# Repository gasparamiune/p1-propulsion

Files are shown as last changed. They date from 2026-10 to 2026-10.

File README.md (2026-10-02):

# P1-J — Waterjet eléctrico inboard para el jet boat de Jorge (2,30 m)

> Paquete de ingeniería del prototipo: cálculo, CAD paramétrico con verificación automática (estado abajo), planos,
> BOM, firmware y pruebas. Todo se regenera desde [`inputs.yaml`](inputs.yaml) con `python run_all.py`. Los números de
> este README se actualizan solos desde `resultados/*.json` (marcadores `<!--V:…-->`).
> **Visor 3D para Jorge** (ensamblado, explotado, pieza por pieza y demo): `04_diseno/visor/` — publicado
> como página web (link en la descripción del PR).

## Resumen ejecutivo

1. **Qué es:** el waterjet que pidió Jorge, rediseñado para que funcione: toma enrasada **entera a proa del impulsor** (su comentario: la rejilla del plano estaba detrás), rampa de 27°, impulsor inox Ø<!--V:sizing.selection.D_imp_mm:.0f-->132<!--/V--> de 5 álabes directo a un motor refrigerado por agua, estator con buje de agua, tobera Ø<!--V:sizing.selection.D_noz_mm:.0f-->87<!--/V-->, boquilla ±25° y bucket de reversa obligatorio (Al 5083 de <!--V:manifest.params.REV_t:g-->8<!--/V--> mm, trabado arriba/abajo por dos émbolos propios con perno Ø<!--V:manifest.params.REV_lock_pin_d:g-->16<!--/V--> que se liberan juntos con un gatillo; cada traba sola aguanta la reversa: D-17c/D-17d; la oreja de la boquilla todavía no llega a FS 2 en el FEA, ver abajo). 12S / 38,4 V (< 50 V CC).
2. **Prestaciones (modelo, sin validar en agua) — el punto débil es el planeo:** con la resistencia **nominal** el bote planea (margen <!--V:sizing.verdict.hump_margin_min_nominal:.0%-->4%<!--/V-->, se piden ≥ 10 %), tarda <!--V:sizing.verdict.t_to_plane_nominal_s:.0f-->23<!--/V--> s y sostiene **<!--V:sizing.verdict.vmax_cont_kmh.nominal:.1f-->24.0<!--/V--> km/h** (~<!--V:sizing.verdict.vmax_peak_kmh.nominal:.0f-->28<!--/V--> km/h por ratos). Con la resistencia **alta** (método sin validar para este casco corto, 02 §3) **no llega a planeo pleno** (se queda en <!--V:sizing.verdict.V_eq_peak_high_kmh:.0f-->20<!--/V--> km/h a fondo y <!--V:sizing.verdict.vmax_cont_kmh.high:.0f-->18<!--/V--> km/h con potencia continua). Ninguna combinación de motor/batería < 50 V cumple el 10 %: lo que lo arregla es el bote — <!--V:sizing.verdict.recovery_mass_text:s-->21 kg menos<!--/V--> o <!--V:sizing.verdict.recovery_lwl_text:s-->L_wl ≥ 1,98 m<!--/V--> (02 §3.2). Lo decide la prueba T4. Autonomía: <!--V:sizing.energy.t_top_min:.0f-->37<!--/V--> min a fondo o <!--V:sizing.energy.t_legal_h:.1f-->2.4<!--/V--> h a 5 kn; empuje a punto fijo <!--V:sizing.performance.bollard_N:.0f-->765<!--/V--> N.
3. **Recomendación:** pedir cotización de la **AWT JT132** (la bomba de la foto de Jorge) con este mismo tren eléctrico: gana la matriz de arquitectura en el <!--V:arch.mc_win_frac.B:.0%-->62%<!--/V--> del Monte Carlo, da <!--V:cmp.B_vmax_kmh:.1f-->26.8<!--/V--> km/h (≈ A ± la curva de AWT, que no está publicada: no es una ventaja demostrada) y baja el costo a ~<!--V:cmp.B_total_eur_min:.0f-->7774<!--/V-->–<!--V:cmp.B_total_eur_max:.0f-->8338<!--/V--> € contra <!--V:bom.total_eur:.0f-->11837<!--/V--> € de construir la bomba propia (<!--V:bom.verified_frac_of_subtotal:.0%-->30%<!--/V--> del subtotal con precio verificado; el resto son servicios de taller a cotizar).
4. **Riesgo n.º 1 — el casco, no la propulsión:** con 0,80 m de manga y el piloto sentado alto, GM ≈ <!--V:sizing.hydrostatics.GM_m:.3f-->0.010<!--/V--> m y capacidad (33 CFR 183.33) de <!--V:sizing.capacity.persons_gear_kg:.0f-->46<!--/V--> kg: **puede volcar**. Ensayo de escora antes de motorizar; probablemente haya que ensanchar el casco o bajar el asiento.
5. **Legal (Dinamarca):** ≤ 5 kn a < 300 m de la costa (perfil "costa" por defecto en el firmware), 4 kn en Als Sund; no es speedbåd (< 19 kW) y probablemente no es "vandscooter" (piloto dentro del casco): confirmar por escrito (research/R13 §8).
6. **Honestidad:** todo está verificado *en software* (CAD de <!--V:manifest.totals.n_parts:d-->65<!--/V--> piezas sin interferencias en <!--V:verify.n_pair_checks:d-->14160<!--/V--> pares×estados, FS ≥ 2 metal / ≥ 3 PETG, tests). **Nada está probado físicamente**; los primeros pasos están en [PENDIENTES_GASPAR.md](PENDIENTES_GASPAR.md).

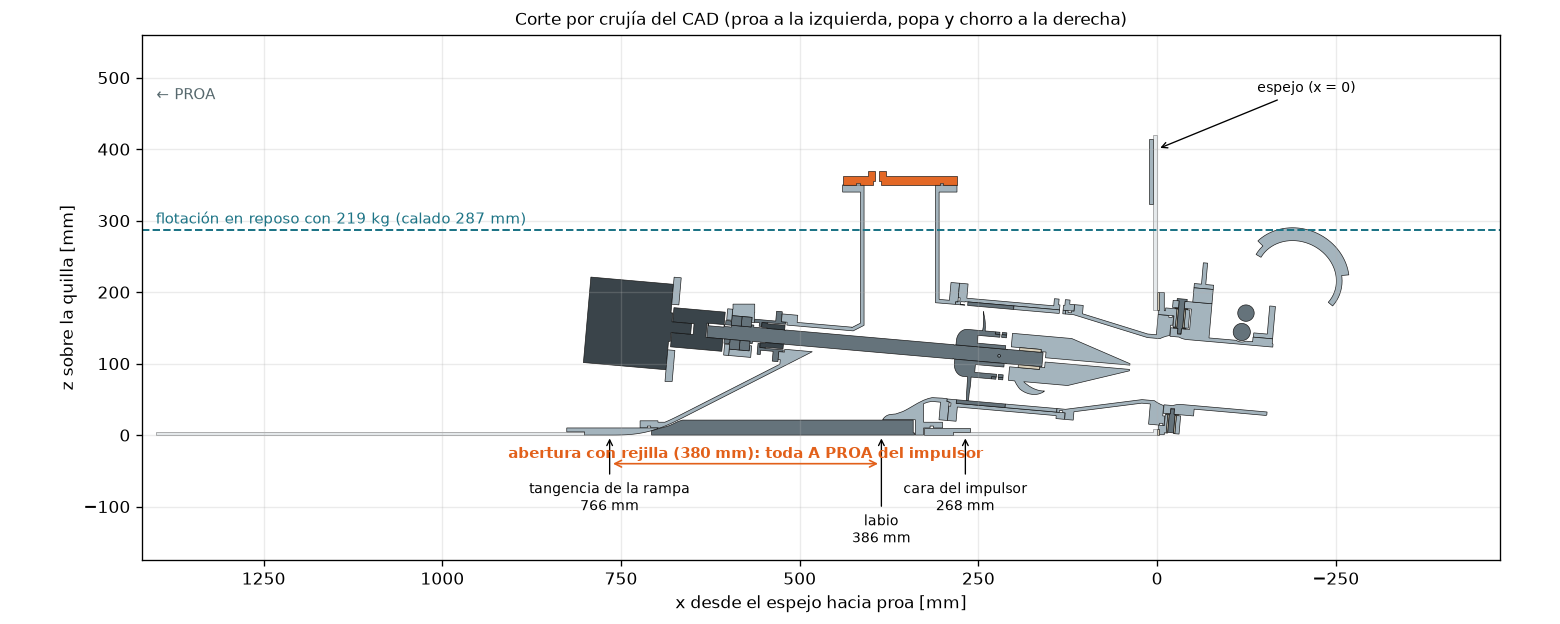
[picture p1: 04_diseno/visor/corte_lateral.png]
Corte por crujía del CAD


## Comprar vs construir

| Opción | Costo total del sistema | V máx. sostenida | Unidad de jet | Comentario |
|---|---|---|---|---|
| **A — bomba propia (este paquete)** | <!--V:bom.total_eur:.0f-->11837<!--/V--> € ≈ <!--V:bom.total_dkk:.0f-->88489<!--/V--> DKK [CALCULADO: bom.py] | <!--V:cmp.A_vmax_kmh:.1f-->24.0<!--/V--> km/h | <!--V:cmp.A_jet_mass_kg:.1f-->22.0<!--/V--> kg | Impulsor y estator CNC 5 ejes + soldaduras: <!--V:bom.services_eur:.0f-->4015<!--/V--> € de servicios de taller [ESTIMADO] sin cotizar |
| **B — AWT JT132 + este tren** | <!--V:cmp.B_total_eur_min:.0f-->7774<!--/V-->–<!--V:cmp.B_total_eur_max:.0f-->8338<!--/V--> € [CALCULADO; precio de la JT132 ESTIMADO] | <!--V:cmp.B_vmax_kmh:.1f-->26.8<!--/V--> km/h (≈ A ± curva AWT) | 12 kg [VERIFICADO: R11 §4] | Trae toma, dirección y reversa; pedir brida, altura del eje y curva de la bomba |
| Lampuga Air (jet boat eléctrico comercial de 2,30 m) | no verificado | ≤ 50 km/h [VERIFICADO: R12] | — | Referencia: 10 kW, 3,6 kWh |

Detalle y matriz ponderada: [03_arquitectura.md](03_arquitectura.md).

## Estado (verificado / no verificado)

| Ítem | Estado |
|---|---|
| Pipeline `run_all.py` (sizing → CAD → FS → planos → verify → BOM → arquitectura → comparación → electrónica → visor → docs) | Ejecuta con exit 0 (bitácora en PROGRESS.md) |
| Dimensionamiento: masas, estabilidad, Savitsky + joroba, waterjet con curva de bomba, cavitación, energía, térmico, eje, pasador | [CALCULADO] `sizing.py`; [02_calculos.md](02_calculos.md) — **calibrar con pruebas T2–T4** |
| CAD: <!--V:manifest.totals.n_parts:d-->65<!--/V--> piezas, STEP + STL, sólidos válidos, impresas ≤ 210×210×260 | [VERIFICADO en software] `verify_parts.py` |
| Interferencias: boquilla −25/0/+25° × bucket arriba/abajo, contra bomba, toma, tren y casco de referencia | [VERIFICADO en software] |
| FS ≥ 3 (impresas) / ≥ 2 (metal) por caso de carga | [CALCULADO] `structural.py` (02 §9); FEA de las piezas críticas en `04_diseno/fea/`. Bucket y boquilla con el criterio de traba única (cada traba sola con todo el momento del chorro, auditoría ronda 4) y el pivote de la ronda 5 (D-17d; en dos piezas, casquillo + muñón, desde la re-auditoría del cierre: auditoria.md MECH-1): cálculo a mano sin filas bajo objetivo; FEA fino: bucket P1-REV-01 FS <!--V:fea.piezas.P1-REV-01.FS_min:.2f-->2.07<!--/V-->, boquilla P1-STE-01 FS <!--V:fea.piezas.P1-STE-01.FS_min:.2f-->2.52<!--/V--> (objetivo 2; desde el cierre de la ronda 5 con el cuerpo del émbolo ajustado Ø<!--V:manifest.params.REV_lock_bore_d:g-->24<!--/V--> H7/h6, sin rosca ni precarga, el piloto Ø<!--V:manifest.params.REV_sp_pilot_d:g-->24<!--/V--> y lóbulos engrosados en las orejas: auditoria.md R5-N1/R5-N5, D-17d) |
| Firmware del acelerador (bucket, perfiles costa/abierto, limpieza de rejilla, kill switch) | [VERIFICADO en software] 69 tests; **sin compilar para AVR** (sin toolchain aquí) |
| Precios | <!--V:bom.verified_frac_of_subtotal:.0%-->30%<!--/V--> del subtotal verificado (research/R11, R08a/b); servicios de taller [ESTIMADO] |
| Casco de Jorge | **Leído de un plano sin escala única: medir todo** (PENDIENTES P0) |
| Estabilidad, estanqueidad, pruebas en agua | **[NO EJECUTADO] — pendiente físico** |

## Cómo correr

```bash
pip install -r requirements.txt          # núcleo (build123d, numpy, trimesh, openplaning, …)
python run_all.py                        # todo, incl. FEA fino: más de una hora; --fast = mallas gruesas y SIN FEA; --skip-render
pytest -q                                # tests (P1_SKIP_SLOW=1 salta la regeneración completa)
```
Tiempo del corrido completo: más de una hora [ESTIMADO]. Solo el FEA fino de las 5 piezas registra <!--V:fea.meta.tiempo_total_s:.0f-->2890<!--/V--> s
[CALCULADO: `meta.tiempo_total_s` de `04_diseno/fea/resultados_fea.json`], y el CAD, los planos y `verify` suman varios minutos más; con `--fast` el
FEA no corre y quedan los resultados anteriores.
Cambiar cualquier dato en `inputs.yaml` (p. ej. `boat.bottom_thickness_mm`, `waterjet.axis_height_m`,
una batería o un motor nuevo) y volver a correr regenera cálculos, selección, geometría, planos, BOM,
visor y documentos (probado: `tests/test_regeneration*.py`, ver [auditoria.md](auditoria.md) §Regeneración).

## Mapa del repositorio

| Archivo | Contenido |
|---|---|
| [01_investigacion.md](01_investigacion.md) + `research/` | Plano de Jorge auditado, toma, métodos de bomba y planeo, componentes y precios, normativa DK |
| [02_calculos.md](02_calculos.md) + `sizing.py`, `p1calc/` | Memoria de cálculo completa |
| [03_arquitectura.md](03_arquitectura.md) | Requisitos, matriz ponderada, comprar vs construir, qué se imprime/mecaniza/compra, riesgos |
| [04_diseno/](04_diseno/README.md) | `params*.py`, `piezas/`, `build_all.py`, `verify_parts.py`, `structural*.py`, planos, electrónica, visor |
| [05_fabricacion.md](05_fabricacion.md) + `prusaslicer/` | Impresión, mecanizado, soldadura, CNC, anodizado, probetas |
| [06_ensamblaje_y_pruebas.md](06_ensamblaje_y_pruebas.md) + [checklist_salida.md](checklist_salida.md) | Montaje, cambios de casco, pruebas T0–T4, FMEA, mantenimiento |
| [07_roadmap_P2.md](07_roadmap_P2.md) | Próxima iteración con disparadores medibles |
| [decisiones.md](decisiones.md) · [auditoria.md](auditoria.md) · [PENDIENTES_GASPAR.md](PENDIENTES_GASPAR.md) | Decisiones, auditoría adversarial, acciones físicas |
| `bom.csv` | Lista de materiales con links, fechas y etiqueta de verificación |

## Próximos pasos físicos (los 5 primeros)

1. **Medir el casco de Jorge** (fondo de 0,25 a 0,85 m del espejo, espejo, astilla muerta, calado en popa con piloto y baterías) → `inputs.yaml` → `python run_all.py`.
2. **Ensayo de escora / estabilidad** con carga desplazada, antes de motorizar.
3. **Pedir cotizaciones**: AWT JT132 (brida de toma, altura del eje, curva), Maytech (potencia continua del motor), taller CNC (impulsor y estator con los STEP).
4. **Consulta legal por escrito** a Søfartsstyrelsen (clasificación y potencia; preguntas en danés en research/R13 §8).
5. **Banco en seco T0** con el controlador, el firmware y el kill switch (acople desconectado: el sello no gira en seco).

## Historia

La versión anterior del proyecto (cola larga eléctrica para un jon boat de 2 personas a 6 km/h) quedó en
el historial de git, commit `5dfada0`. Este paquete la reemplaza a pedido del usuario: el motor que necesita
Jorge es un waterjet inboard.

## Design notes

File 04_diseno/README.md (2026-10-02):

# 04 — Diseño detallado (waterjet P1-J)

Todo se regenera con `python run_all.py` desde la raíz (corrido completo con FEA fino: más de una hora; `--fast` usa
mallas gruesas y no corre el FEA); cada script también corre solo.

| Archivo | Qué hace |
|---|---|
| `params.py` | Deriva la geometría de `inputs.yaml` + `resultados/sizing.json` (D impulsor, D tobera, eje, toma, alturas) y carga los módulos `params_toma/bomba/tren/direccion.py` (`extend(d)`), que agregan las interfaces de cada grupo. Define los marcos: **BOTE** (x hacia proa desde la cara exterior del espejo, z desde la quilla) y **JET** (origen en la cara de entrada del impulsor, X hacia popa por el eje); `loc_jet`, `loc_steer`, `loc_bucket`. |
| `piezas/P1-<SUB>-<NN>_<nombre>.py` | Un script por pieza: `META` (id, material, proceso impresa/torneada/comprada/referencia, cantidad, marco boat/jet/drive/steer/bucket, grupo, `allow`), `build()`, `placements()`, `checks()`. SUB: INT toma · PMP bomba · DRV tren · MOT motor · STE dirección · REV reversa · CTL mandos · ELE electrónica · BAT batería · REF casco de referencia. |
| `build_all.py` | Exporta STEP + STL (orientación de impresión), `step/P1-ASM_marcha.step.gz` y `resultados/manifest.json` (masas CAD por grupo). |
| `verify_parts.py` | Exit ≠ 0 si falla: sólido válido/manifold, envolvente de impresora, `checks()` de cada pieza, interferencias en todos los estados (boquilla −25/0/+25° × bucket arriba/abajo) contra bomba, toma, tren y casco. |
| `structural.py` + `structural_*.py` | FS por pieza y caso de carga (≥ 3 PETG, ≥ 2 metal) → 02 §9. FEA de las piezas críticas en `fea/`. |
| `planos.py` + `planos_*.py` | Planos SVG acotados de las piezas mecanizadas/soldadas → `planos/`. |
| `electronica/` | Cableado, cálculo de cables/fusibles, firmware del acelerador (perfil costa/abierto, bucket, kill). |
| `probetas/` | Probetas de PETG (holguras, roscas, O-ring) para calibrar antes de imprimir las piezas. |
| `visor/` | `build_visor.py` → visor web 3D (ensamblado, explosión, dirección, bucket, demo) para Jorge. |

## Lista de piezas

<!-- AUTO:parts_totals -->
Total impreso: **1.05 kg** de PETG, **58 h** de impresión (a 18.0 g/h); masa de la unidad de jet (CAD, sin motor): **26.11 kg**.
<!-- /AUTO:parts_totals -->

<!-- AUTO:parts_list -->
| ID | Función | Envolvente [mm] | Material | Proceso | Cant. | Caso de carga dominante | Orientación de impresión | g c/u | h c/u |
|---|---|---|---|---|---|---|---|---|---|
| P1-BAT-01_bateria | Batería LFP de la selección (modelo de referencia, una por rama) | 532×207×215 | referencia | comprada | 2 | — | — | 19800 | — |
| P1-CTL-01_placa_espejo | Placa interior del espejo para M66 + 2 prensaestopas (Al 5083 6 mm) | 6×351×90 | Al 5083 | torneada | 1 | Reacción del M66 (momento de dirección / brazo) en el espejo | — | 489 | — |
| P1-CTL-02_caja_acel | Caja PETG de palancas con sensor hall | 184×82×68 | PETG | impresa | 1 | Mano apoyada 150 N sobre la tapa [SUPUESTO: structural_direccion, FEA]; sin cargas de mando (van a P1-CTL-08) | Tapa sobre la cama (ranuras planas, sin soportes); ala arriba. 0,2 mm, 5 perímetros, 30 % giroide | 134 | 7.4 |
| P1-CTL-03_soporte_kill | Soporte PETG del kill switch con cordón y de la seta | 100×130×55 | PETG | impresa | 1 | Tirón del cordón 150 N [SUPUESTO] + golpe de mano sobre la seta 200 N [SUPUESTO] | Base sobre la cama; la cara inclinada a 45° no necesita soportes. 0,2 mm, 5 perímetros | 120 | 6.7 |
| P1-CTL-04_pasamuros_m66 | Pasamuros 316 del M66 (brida, M20, rosca 7/8" UNF) | 43×32×32 | AISI 316 | torneada | 1 | Tiro/empuje del M66 contra la placa del espejo | — | 128 | — |
| P1-CTL-05_prensaestopas | Prensaestopas M16 IP68 (comprado) | 27×24×24 | referencia | comprada | 2 | — | — | 15 | — |
| P1-CTL-06_terminal_m66 | Tubo terminal del cable M66 (comprado) | 230×22×22 | Acero | comprada | 1 | — | — | 350 | — |
| P1-CTL-07_terminal_mach5_consola | Terminal Mach5 en la consola — comprado | 22×22×140 | Acero | comprada | 1 | — | — | 120 | — |
| P1-CTL-08_placa_central | Placa central de palancas Al 5083 6 mm (eje, enclavamiento, grapas Mach5) | 120×77×182 | Al 5083 | torneada | 1 | Fuerza de mano 100 N en el pomo (150 mm) contra el enclavamiento | — | 219 | — |
| P1-CTL-09_palanca_acel | Palanca del acelerador Al 6061 8 mm | 60×8×191 | Al 6061-T6 | torneada | 1 | 100 N en el pomo (150 mm) [SUPUESTO] | — | 102 | — |
| P1-CTL-10_palanca_bucket | Palanca del bucket Al 6061 8 mm con manivela del Mach5 | 79×49×165 | Al 6061-T6 | torneada | 1 | 100 N en el pomo contra el enclavamiento / tope | — | 137 | — |
| P1-CTL-11_eje_palancas | Eje Ø12 con cabeza portaimán (316) | 18×38×18 | AISI 316 | torneada | 1 | Flexión y torsión: 100 N en el pomo del acelerador | — | 39 | — |
| P1-CTL-12_perno_enclav | Perno de enclavamiento Ø6 × 13 (316) | 6×13×6 | AISI 316 | torneada | 2 | Corte: 100 N en el pomo del bucket contra el enclavamiento | — | 3 | — |
| P1-CTL-13_varilla_consola | Varilla Ø6,4 + rótula M6 del Mach5 en la consola (comprada) | 18×8×130 | AISI 316 | comprada | 1 | — | — | 40 | — |
| P1-CTL-14_gatillo | Gatillo del desbloqueo (Al 6061 6 mm) con barra igualadora 316 de los dos Bowden | 47×10×56 | Al 6061-T6 | torneada | 1 | Apriete de la mano 100 N [SUPUESTO] en la hoja; tiro de los dos cables por la barra igualadora | — | 13 | — |
| P1-CTL-20_consola_ref | Consola (referencia, medir la real) | 250×360×532 | referencia | referencia | 1 | — | — | 0 | — |
| P1-CTL-21_volante_ref | Volante Ø320 + timonería T85 (referencia) | 242×320×320 | referencia | referencia | 1 | — | — | 0 | — |
| P1-DRV-01_shaft | Eje Ø20 AISI 316 torneado: impulsor (pasador de corte) → sello → 2×7204 → acople | 470×26×26 | AISI 316 | torneada | 1 | Par T_max del controlador y par de corte del pasador; empuje Fa a punto fijo; velocidad crítica | — | 1181 | — |
| P1-DRV-02_seal_housing | Caja del sello mecánico 316: espigón Ø42, brida 4×M6, cámara mojada, linterna de goteo | 44×70×70 | AISI 316 | torneada | 1 | Presión de diseño de la bomba 0,2 MPa + resorte del sello; bulones M6 al buje de la toma | — | 311 | — |
| P1-DRV-03_bearing_bracket | Pórtico Al 6082 sobre el conducto: alojamiento 2×7204 BECBP, 4×M8 a la placa base | 150×296×173 | Al 5052/6082 | torneada | 1 | Empuje Fa a punto fijo + reacción radial + 3 g vertical del tren; bulones M8 a la placa base de Al | — | 1642 | — |
| P1-DRV-04_bearing_7204BEP | Rodamiento SKF 7204 BECBP apareable universal (par en O), comprado | 14×47×47 | Acero | comprada | 2 | Empuje Fa + reacción radial (L10 en sizing) | — | 110 | — |
| P1-DRV-05_locknut_KM4 | Tuerca KM4 M20×1 + arandela MB4 (comprada) | 8×32×32 | Acero | comprada | 1 | Empuje en reversa (≤ Fa) y precarga | — | 25 | — |
| P1-DRV-06_bearing_cover | Tapa delantera Al de rodamientos (4×M5), toma el empuje hacia proa | 7×65×65 | Al 5052/6082 | torneada | 1 | Empuje Fa a punto fijo hacia proa: flexión de la tapa entre el aro y los M5 | — | 44 | — |
| P1-DRV-07_mech_seal_MG1_20 | Sello mecánico MG1 Ø20 carbón/SiC (comprado) | 32×35×35 | referencia | comprada | 1 | Presión del conducto, 5 m/s | — | 60 | — |
| P1-DRV-08_coupling_rotex24 | Acople Rotex 24 Ø20 / Ø motor (comprado; cubo de eje refrentado) | 72×55×55 | referencia | comprada | 1 | Par T_max del controlador; par de corte del pasador (pico) | — | 600 | — |
| P1-ELE-01_esc_stand | Base elevada PETG del controlador IP65 (4 × M6 al piso, 4 insertos M5 para la capota) | 208×138×60 | PETG | impresa | 1 | Peso del ESC + capota a 3 g vertical y 1 g lateral; tirón de cables | Base abierta sobre la cama; tablero arriba (puentes de 3,2 mm entre nervios, sin soportes). | 263 | 14.6 |
| P1-ELE-02_esc_hood | Capota antisalpicaduras PETG del controlador (4 × M5 a la base) | 208×126×55 | PETG | impresa | 1 | Apriete de la almohadilla EPDM (4 × M5) y 3 g vertical del ESC hacia arriba (golpe de ola) | Techo sobre la cama, paredes y nervios hacia arriba (sin soportes). | 207 | 11.5 |
| P1-ELE-03_cooling_outlet | Pasacasco 316 de salida del agua de refrigeración (testigo en el espejo) | 37×28×28 | AISI 316 | comprada | 1 | — | — | 45 | — |
| P1-ELE-04_esc | Controlador VESC de la selección (FSESC 75350 con caja de agua) | 200×95×50 | referencia | comprada | 1 | — | — | 2000 | — |
| P1-INT-01_conducto | Conducto de toma enrasada Al 5083 soldado: rampa C2, transición a Ø D_bore, brida bomba, buje del sello, chimenea de inspección | 447×198×350 | Al 5083 | torneada | 1 | Presión interna −p_pump_max…+p_pump_max, golpe de fondo, 3 g agua; empuje NO pasa por acá | — | 4699 | — |
| P1-INT-02_placa_base | Placa base de la toma Al 5083 10 mm: cuerpo enrasado + ala abulonada al casco, cuña de la rampa, roscas del conducto y del soporte de rodamientos | 565×350×10 | Al 5083 | torneada | 1 | Golpe de fondo, empuje del tren por el soporte de rodamientos, tracción de los bulones del conducto | — | 3042 | — |
| P1-INT-03_rejilla | Rejilla 316: pletinas perfiladas 4 × 21 longitudinales (luz ≤ 12,5) enrasadas, pletina de popa y tirante de proa, 4 × M5 A4 aislados | 368×182×21 | AISI 316 | torneada | 1 | Rejilla tapada a la presión de cierre de la bomba; golpe de objeto 200 N en el centro de una barra | — | 2014 | — |
| P1-INT-04_tapa_inspeccion | Tapa PETG Ø160 × 10 de la chimenea de inspección, O-ring de cara, 4 × M6 | 160×160×19 | PETG | impresa | 1 | Presión interna de la toma (succión de cierre / recuperación a 30 km/h) sobre Ø de la junta | Cara de la ranura del O-ring y del hexágono de la tuerca sobre la cama (fondos lisos), resalte arriba, 100 % relleno | 327 | 18.2 |
| P1-MOT-01_motor | Motor de la selección (MTI120116: Ø120 × 116, refrigerado por agua) | 146×120×120 | referencia | comprada | 1 | Par de reacción T_max sobre P1-MOT-02; 3 g vertical | — | 4400 | — |
| P1-MOT-02_motor_mount | Soporte del motor Al: placa a la cara del motor + pies al piso (4×M8) | 76×190×146 | Al 5052/6082 | torneada | 1 | Par de reacción T_max del controlador + 3 g vertical del motor; sin empuje | — | 842 | — |
| P1-PMP-01_housing | Carcasa Al 6061-T6: brida de la toma, asiento del anillo y del estator, puerto de agua | 166×193×193 | Al 6061-T6 | torneada | 1 | Presión interna 0,2 MPa; reacción del estator; momentos de boquilla/bucket en bridas | — | 1492 | — |
| P1-PMP-02_wear_ring | Anillo de desgaste 316 torneado, prensado en la carcasa; holgura de punta tip_clr | 69×143×143 | AISI 316 | torneada | 1 | Presión de la bomba (apoyado en la carcasa); roce de piedras | — | 1187 | — |
| P1-PMP-03_impeller | Impulsor axial de 5 álabes, cubo Ø66 con nariz, 2 semipasadores de corte (sin chavetero) | 69×132×132 | AISI 316 | torneada | 1 | Par máx. del controlador + empuje axial; corte del pasador (piedra) | — | 1335 | — |
| P1-PMP-04_pin_band | Anillo retén 316 que tapa los extremos del pasador de corte | 16×66×66 | AISI 316 | torneada | 1 | Centrífuga a n máx.; retención del pasador | — | 76 | — |
| P1-PMP-05_shear_pin | 2 semipasadores de corte Al 6061-T6 (fusible de par del impulsor, cambiables en el eje) | 4×30×4 | Al 6061-T6 | torneada | 2 | Par del controlador (no corta); corta a T_cut (piedra) | — | 1 | — |
| P1-PMP-06_stator | Estator Al 6061-T6 de 7 álabes con camisa, cubo con buje de agua y cono de cola | 169×143×143 | Al 6061-T6 | torneada | 1 | Reacción del par del rotor en los álabes; carga radial del buje; presión | — | 1524 | — |
| P1-PMP-07_water_bushing | Buje Ø20 lubricado por agua en el cubo del estator (2.º apoyo del eje) | 30×28×28 | POM-C | torneada | 1 | Carga radial del eje (desbalance + hidráulica) | — | 12 | — |
| P1-PMP-08_fixed_nozzle | Tobera fija Al: contracción a D_noz, rótula de la boquilla y resalte del sello de espejo | 151×161×161 | Al 6061-T6 | torneada | 1 | Presión interna 0,2 MPa; reacción de la placa de espejo por el O-ring | — | 1408 | — |
| P1-PMP-09_transom_plate | Placa de espejo Al 5083 con cuello coaxial, sello radial sobre la tobera y orejas de pivote | 44×216×199 | Al 5083 | torneada | 1 | F lateral de la boquilla y F del bucket en las orejas; sello del casco | — | 449 | — |
| P1-PMP-10_transom_gasket | Junta NBR 2 mm del espejo (bajo la placa P1-PMP-09) | 2×216×199 | NBR | comprada | 1 | Compresión de los 6 × M6 | — | 35 | — |
| P1-PMP-11_pivot_bushing | Buje POM-C de pivote de la boquilla en las orejas de la placa de espejo (×2) | 12×12×26 | POM-C | torneada | 2 | F lateral de la boquilla / F del bucket (aplastamiento) | — | 2 | — |
| P1-REF-01_casco | Casco de referencia (popa 1,4 m): fondo con astilla muerta y paño plano, pantoque, costados, espejo; recorte de la toma y agujero del espejo | 1400×798×516 | referencia | referencia | 1 | — | — | 0 | — |
| P1-REV-01_bucket | Bucket de reversa Al 5083 8 mm (cuchara + brazos + nervio), traba en cada brazo (cada una lleva todo M_h) | 203×151×170 | Al 5083 | torneada | 1 | Chorro desviado en reversa (R12: 1,4 kN, M_h por cantidad de movimiento) con UNA traba; presión dinámica en la chapa | — | 1241 | — |
| P1-REV-02_perno_bucket | Pivote del bucket en dos piezas de dúplex 1.4462: casquillo (brida Ø36 × 4, piloto Ø24 h6, Ø20 H7 ciego) + muñón Ø20 h7; tornillo M12 A4-80 + tuerca baja ISO 4035 con Loctite | 37×68×37 | Dúplex 1.4462 | torneada | 2 | Reacción del pivote = chorro/2 + traba con M_h completo (R12, una traba sola): flexión del muñón y apertura de la unión | — | 218 | — |
| P1-REV-03_buje_bucket | Buje con brida POM-C del pivote del bucket (Ø20,1/Ø24 × 18 + brida Ø30 × 1), escariado después de prensar | 30×19×30 | POM-C | torneada | 2 | Presión: reacción del pivote (chorro/2 + traba con M_h completo, R12 y reversa de sizing) | — | 4 | — |
| P1-REV-04_embolo | Émbolo de traba propio: cuerpo ajustado Ø24 h6 (Loctite 641, collar exterior + anillo DIN 471) y perno Ø16 h9 en AISI 316 + resorte inox, uno por oreja ±Y | 33×76×33 | AISI 316 | torneada | 2 | Perno Ø16: flexión + corte con M_h completo en una traba (R12) / REV_lock_r; cuerpo: aplastamiento en la oreja | — | 264 | — |
| P1-REV-05_soporte_mach5 | Soporte de la vaina del Mach5 (Al 5083 6 mm) | 80×101×129 | Al 5083 | torneada | 1 | Reacción del cable al mover el bucket (sin carga del chorro: la toma el émbolo) | — | 190 | — |
| P1-REV-06_perno_varilla | Tornillo con hombro Ø8 × 10 / M6 (316) | 13×26×13 | AISI 316 | torneada | 1 | Fuerza de maniobra del Mach5 (bucket sin carga del chorro) | — | 10 | — |
| P1-REV-07_terminal_mach5 | Terminal Mach5 (vaina + cabeza) en la boquilla — comprado | 22×22×140 | Acero | comprada | 1 | — | — | 120 | — |
| P1-REV-08_varilla_mach5 | Varilla Ø6,4 + rótula M6 del Mach5 (comprada) | 18×8×94 | AISI 316 | comprada | 1 | — | — | 40 | — |
| P1-REV-09_soporte_bowden | Soporte de reenvío del desbloqueo: base + montante Al 5083 soldados, 2 balancines 1:1 y 2 pestañas de reguladores M6 | 48×76×51 | Al 5083 | torneada | 1 | Tiro de diseño por cable (mano 100 N en el gatillo P1-CTL-14 repartida por el igualador) [CALCULADO] | — | 96 | — |
| P1-REV-10_bowden_embolo | Bowden inox de liberación de cada émbolo (extremo de la boquilla, comprado; ×2) | 55×10×86 | AISI 316 | comprada | 2 | — | — | 60 | — |
| P1-STE-01_boquilla | Boquilla direccional con orejas de pivote, torre del yugo y orejas del bucket | 144×110×170 | Al 6061-T6 | torneada | 1 | Desvío del chorro F_steer (R12: 364 N) + pivote y traba del bucket con M_h completo en una traba (R12) | — | 1165 | — |
| P1-STE-02_perno_sup | Tornillo con hombro Ø8 / M6 del pivote superior (316 estirado) | 14×14×49 | AISI 316 | torneada | 1 | Flexión en doble apoyo + corte: reacción superior (bucket R12 + dirección) | — | 20 | — |
| P1-STE-03_arandela_pom | Arandela de empuje POM-C Ø8,4/Ø18 × 1 | 18×18×1 | POM-C | torneada | 3 | Empuje axial: peso de la boquilla + bucket y componente vertical del chorro | — | 0 | — |
| P1-STE-04_brida_yugo | Brida del yugo de dirección (Al 5083 20 mm) | 56×136×20 | Al 5083 | torneada | 1 | Par de dirección + flexión del poste (biela M66) | — | 173 | — |
| P1-STE-05_perno_inf | Espárrago con hombro Ø8 / M6 del pivote inferior (316) | 8×8×33 | AISI 316 | torneada | 1 | Flexión en voladizo + corte: F_s/2 | — | 11 | — |
| P1-STE-06_poste | Poste del yugo Ø22 con brida Ø44 y M16 (6061-T6) | 44×44×140 | Al 6061-T6 | torneada | 1 | Flexión + torsión por la fuerza de la biela del M66 | — | 151 | — |
| P1-STE-07_brazo | Brazo del yugo con rótula M8 (Al 5083 10 mm) | 61×32×10 | Al 5083 | torneada | 1 | Fuerza de la biela del M66 (momento de dirección / brazo) | — | 34 | — |
| P1-STE-08_tope_direccion | Topes de dirección ±δmax+1,5° (Al 5083 8 mm) | 157×92×32 | Al 5083 | torneada | 1 | Timón forzado contra el tope: 2 × fuerza de la biela del M66 [SUPUESTO] | — | 82 | — |
<!-- /AUTO:parts_list -->

## Verificación

<!-- AUTO:verify -->
Resultado: **OK** — 65 piezas, 14160 pares×estados de interferencia; boquilla δ ∈ [-25.0, 0.0, 25.0]°, bucket {arriba, abajo}; masa de la unidad de jet (CAD) 26.11 kg.
<!-- /AUTO:verify -->

## Ajustes (los del CAD; confirmar con el taller y, en PETG, con probetas)

| Unión | Ajuste CAD | Nota |
|---|---|---|
| Eje Ø20 ↔ 2 × 7204 BECBP (en O, apareables universales) | muñón Ø20 k5 / alojamiento Ø47 H7 | Práctica de catálogo para aro interior rotante [SUPUESTO]; precarga ligera de fábrica, KM4 apretado contra el collar |
| Eje ↔ sello MG1 y tramo mojado | Ø20 h8 | Tolerancia de catálogo del sello [SUPUESTO: confirmar con la hoja del MG1] |
| Eje ↔ buje de agua POM-C del estator | muñón f7 / buje H7 | 2.º apoyo; el buje se cambia como consumible |
| Impulsor ↔ eje | deslizante; par por 2 semipasadores de corte Al 6061 en agujeros H8 escariados | Sin chaveta: los semipasadores son el fusible de par (02 §8) |
| Anillo de desgaste ↔ carcasa | prensado ligero + retenedor anaeróbico [ESTIMADO] | Holgura de punta = `tip_clr` (inputs) |
| Caja del sello ↔ buje de la toma | espigón f7 / H8 + 4 × M6 | Concentricidad del sello |
| Carcasa ↔ conducto (brida de la bomba) | espigón Ø140 h6 en rebaje H7 + 8 × M6 | Centra la bomba con el sello y el pórtico (alinear el pórtico con mandril al buje del estator) |
| Tobera ↔ carcasa | espiga de 12 mm con O-ring radial cs 3,53 + 8 × M5 | La tobera sale por el agujero del espejo para el servicio |
| Pivotes de la boquilla | pernos 316 con hombro (P1-STE-02/05) en bujes POM-C | Holgura de buje según plano |
| Pivote del bucket (P1-REV-02/03) ↔ oreja de la boquilla | pivote en **dos piezas** de dúplex 1.4462 (re-auditoría del cierre de la ronda 5, MECH-1): **casquillo** con piloto Ø<!--V:manifest.params.REV_sp_pilot_d:g-->24<!--/V--> h6 en Ø<!--V:manifest.params.REV_sp_pilot_d:g-->24<!--/V--> H7 escariado en el lóbulo engrosado del pivote (<!--V:manifest.params.STE_piv_t:g-->20<!--/V--> mm, hacia adentro de la placa de <!--V:manifest.params.STE_ear_t:g-->14<!--/V--> mm; R5-N5), con **Loctite 641** (llena el juego: FEA-4), del mismo largo que el lóbulo (fondo enrasado con la cara interior), brida Ø<!--V:manifest.params.REV_sp_fl_d:g-->36<!--/V--> × <!--V:manifest.params.REV_sp_fl_t:g-->4<!--/V--> contra la cara exterior (Tef-Gel en la brida) y agujero Ø<!--V:manifest.params.REV_pin_d:g-->20<!--/V--> H7 ciego; se monta antes del bucket; **muñón** Ø<!--V:manifest.params.REV_pin_d:g-->20<!--/V--> h7 en el casquillo (Tef-Gel), que entra después del bucket por el buje POM-C Ø<!--V:manifest.params.REV_bush_od:g-->24<!--/V--> × <!--V:manifest.params.REV_bush_L:g-->18<!--/V--> (prensado con 0,05–0,10 de interferencia en Ø24 H7 y escariado después de prensar); ISO 4017 M12 × 60 A4-80 (`P1-REV-02.bolt_len_iso`) con ISO 7089 sobre el muñón + arandela ancha ISO 7093 sobre el fondo del casquillo y la cara interior del lóbulo + tuerca baja ISO 4035 M12 A4-035 (m <!--V:manifest.params.REV_nut_h:g-->6<!--/V--> mm, para que siga el M12 × 60) a <!--V:est.loads.structural_direccion.bolt_torque_Nm:.0f-->12<!--/V--> N·m con Loctite 243 | El corte y el momento del pivote los lleva el apoyo del piloto en la oreja (camino de carga diseñado); la unión de la brida no se cuenta y el tornillo solo retiene (D-17d, re-auditoría ronda 5); orden de montaje casquillos → bucket → muñones (06 M13) |
| Trabas del bucket (P1-REV-04 ↔ P1-REV-01 / P1-STE-01) | perno Ø<!--V:manifest.params.REV_lock_pin_d:g-->16<!--/V--> h9 en agujero Ø<!--V:manifest.params.REV_lock_hole_d:g-->16.5<!--/V--> del brazo (con juego, a propósito); cuerpo **ajustado** Ø<!--V:manifest.params.REV_lock_bore_d:g-->24<!--/V--> h6 en el Ø<!--V:manifest.params.REV_lock_bore_d:g-->24<!--/V--> H7 liso del lóbulo engrosado de la traba (<!--V:manifest.params.STE_lock_t:g-->23.5<!--/V--> mm: 3 por fuera de la placa y 6,5 por dentro; R5-N5; cuerpo de un solo Ø, como el piloto) con Loctite 641, collar exterior Ø32 × 1,5 contra la cara exterior del lóbulo (1 mm de luz al brazo) y arandela 316 + anillo DIN 471-24 A4 contra su cara interior; sin rosca ni precarga (cierre de la ronda 5, R5-N1; antes cuerpo M24×1,5 apretado a 110 N·m contra un collar interior); pomo de 316 Ø23 (pasa por el agujero: el émbolo armado entra desde afuera) roscado a fondo en la cola (M10×1, Loctite 243; cola de 42 mm que apoya en el fondo del pomo, MECH-2); cola del perno con rosca M4 axial de 12 mm para el eslabón rígido del desbloqueo (P1-REV-09, ajuste ±2 mm; MECH-6); ranura del anillo a 24,6 (+0,1/0) de la cara de apoyo del collar (MECH-5), hexágono 6 × 6 en la punta del perno y tapa con 2 × Ø3 y Loctite 243 (MECH-7); garganta R14 en el tubo de P1-STE-01 bajo el émbolo −Y (2 mm de luz, MECH-3) | Criterio de traba única: cada traba sola lleva todo M_h, así que el desfase entre las dos no importa para la resistencia; el cuerpo lleva la fuerza y el momento del perno a la oreja por aplastamiento, como el piloto; prueba funcional (los dos pernos entran solos arriba y abajo) |
| Piezas PETG (capota, base ESC, caja, tapa) | 0,25 mm diametral sobre metal | Peine de holguras de `probetas/`; roscas por tuerca A4 cautiva, nunca Loctite 243 sobre PETG |

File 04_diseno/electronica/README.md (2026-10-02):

# 04_diseno/electronica — Electrónica, cadena de seguridad y control de P1

**Estado:** diseño + firmware + tests de lógica. **[NO EJECUTADO en hardware]**: nada de esto se probó todavía con componentes reales. Lo verificado: la lógica v2.0 compila en C99 estricto con gcc (`-Wconversion -Werror`) y `pytest -q tests/test_firmware.py` pasa (§5.8). **El sketch v2.0 NO se compiló para AVR** (en esta máquina no hay `arduino-cli` ni `avr-gcc`; el test AVR se salta): la cifra de 11 270 B de flash que figuraba acá era de la v1 (arduino-cli 1.5.2, sesión anterior) y no aplica a v2.0 — compilar en T0.0 (§5.5). Los parámetros del VESC se leyeron en el código fuente del firmware (`vedderb/bldc`, rama master, 2026-10-01).

Etiquetas: **[VERIFICADO: fuente]** · **[CALCULADO]** · **[ESTIMADO: base]** · **[SUPUESTO]**. Las tablas entre marcas `ELEC:` las genera `calc_electronica.py` desde `inputs.yaml` y `resultados/sizing.json`: no editarlas a mano.

| Archivo | Qué es |
|---|---|
| [`diagrama_cableado.svg`](diagrama_cableado.svg) | Diagrama de cableado: potencia, cadena de emergencia, control, sistema flotante |
| `diagrama_cableado.py` | Lo genera (svgwrite); rótulos leídos de `calc_electronica.compute()` |
| `calc_electronica.py` | Configuración del VESC, precarga, bobina, optos, presupuesto de corte, tabla de verdad; escribe `electronica.json`, `tabla_verdad.csv` y los bloques `ELEC:` de este README (`--check` solo verifica) |
| `firmware/throttle_logic.h`, `.c` | Lógica pura C99 v2.0 del waterjet (armado, rampa, zona muerta, expo, bucket: límite y retención, limpieza de rejilla, perfil costa/abierto, dwell, fallas de sensor, watchdog lógico) |
| `firmware/p1_throttle/p1_throttle.ino` | Sketch Arduino Nano: E/S (hall, cordón/seta, fin de carrera del bucket D5, selector D7, pulsador de rejilla D8, perfil D12), PPM por Timer1, interrupciones del cordón/seta, WDT de hardware, LED, calibración |
| `firmware/vesc_perfil.lisp` | Script LispBM del VESC (FW ≥ 6.00): lee D12 por ADC1 y cambia `l_max_erpm` entre COSTA y ABIERTO (§5.4); sus dos topes de ERPM los **reescribe** `calc_electronica.py` |
| `firmware/p1_throttle/src/` | Copia idéntica de la lógica (el IDE de Arduino solo compila dentro de la carpeta del sketch). Un test exige que sea idéntica |
| `../../tests/test_firmware.py` | 69 tests (lógica ejecutada desde Python vía gcc + ctypes, coherencia con `calc_electronica`/`electronica.json` y vigencia de lo generado) + 1 de compilación AVR opcional |

Regenerar: `python 04_diseno/electronica/calc_electronica.py && python 04_diseno/electronica/diagrama_cableado.py` (no están en `run_all.py`: ver §11).

---

## 1. Diagrama de cableado

Diagrama de cableado de P1

[Abrir `diagrama_cableado.svg`](diagrama_cableado.svg)

Lectura rápida, de izquierda a derecha:

1. **Potencia (rojo/negro grueso):** dos baterías LiTime 36 V (12S, 36,0–43,8 V) **en paralelo** (12S2P). Cada batería: borne + → **F_BR** (Class T de rama en portafusible Blue Sea 5007100, a ≤ 178 mm del borne [VERIFICADO: R06 §5.1, ABYC E-11 7 in; el texto de ABYC lo escribe "175 mm" → montar a ≤ 175 mm]) → cable de rama de 35 mm² → **barra +**; borne − → 35 mm² → **barra −**. Barra + → **F1** (Class T junto a la barra, protege el cable de 70 mm²) → **S1** desconectador → **K1** contactor monoestable con **R_pre** en paralelo → VESC → 3 fases → motor. Barra − → VESC B−. El antichispa no se usa (100 A < I de batería). Cables de rama de igual largo y sección (reparto de corriente, §6 `l_in_current_max`). **Fusibles Class T y no MRBF:** el cortocircuito presunto de las dos baterías llega a ≈ 8,8 kA y el MRBF corta solo 2 kA a 58 V (§7, auditoría R2-E3). **Toma de carga** Anderson SB50 (B-ANDERSON) en las barras +/−, aguas arriba de F1/S1, con su propio fusible **F6** (gPV 32 A, B-CHGFUSE) en la barra +: su cable de ≤ 16 mm² no lo protegen los F_BR.
2. **Mando de 12 V (naranja):** **B-12V** (Mean Well **RSD-60L-12**, entrada 18–72 V [VERIFICADO: Mean Well RSD-60-SPEC 2026-07-09; la RSD-60G es de 9–36 V y no sirve con 12S], conectado a la barra + aguas ARRIBA de F1/S1 con su fusible F5 removible) → **F2** → **retención** (Schottky 1N5822 + 22 mF, B-HOLD: sostiene la bobina ≥ 9 V durante el hueco del riel cuando arranca la bomba de achique contra el límite de corriente del DC-DC, §7) → **SETA** (NC) → nodo **N1** → J2 → **CORDÓN** (cerrado con el clip puesto) → J2 → nodo **N2** → **bobina de K1** (EV200AAANA, 9–36 V con economizador) → 12 V−. Cualquier apertura de esa serie (clip afuera, seta pulsada, cable cortado, conector suelto, F2 fundido, bobina abierta, B-12V sin salida) deja la bobina sin corriente y K1 abre: es el corte **por hardware** que pide R06 §3.2 y §3.5. El cordón y la seta conmutan 12 V (cierre 3,8 A ≤ 130 ms, retención 0,13 A) y al abrir no ven sobretensión inductiva (el economizador limita la fuerza contraelectromotriz a 0 V [VERIFICADO: hoja EV200]): así el interruptor Watski de 12 V – 15 A trabaja dentro de su valor nominal (auditoría H3). Como B-12V está aguas arriba de S1, con S1 abierto y el clip puesto K1 cierra igual (sin efecto: el bus está cortado por S1) y la bobina consume 1,6 W: **sacar el clip al dejar el bote**.
3. **Sensado y redundancia (azul):** el opto **U1** ve N1 (seta) → D3 del Nano; **U2** ve N2 (cordón + seta) → D2; **U3** también ve N2 y está **en serie** con el transistor **Q_EN** (comandado por D4 del Nano) entre la entrada **ADC2** del VESC y GND. ADC2 tiene pull-up de 10 kΩ a 3,3 V: si cualquiera de los dos deja de conducir, ADC2 > 1,65 V → **kill por software del VESC** [VERIFICADO: `timeout.c`, `KILL_SW_MODE_ADC2_HIGH`].
4. **Control:** DC-DC 43,8→5 V (RECOM R-78HB, 9–72 V; alimentado **aguas arriba de K1**, después de S1 y F3) → Nano y sensor hall A1324 de la palanca del acelerador. PPM por D9 → VESC (pull-down de 10 kΩ en el lado del VESC: con el MCU en reset no hay pulsos). El 5 V del VESC **no** se une al 5 V del Nano. Consola: **fin de carrera del bucket** (NC, cerrado = arriba) → D5; **selector de perfil** COSTA/ABIERTO → D7; **pulsador de limpieza de rejilla** → D8; **D12 → ADC1 del VESC** (10 kΩ serie + 20 kΩ a GND ≈ 3,3 V) para el perfil, leído por `firmware/vesc_perfil.lisp`. La marcha atrás es el **bucket**: el motor gira siempre en avance (salvo la limpieza de rejilla, lenta y ≤ 3 s) y con el bucket abajo el MCU limita el comando a `reverse_limit` (§5.2).
5. **Sistema flotante:** BAT− **no** se conecta al casco de aluminio [VERIFICADO: R06 §5.1, ISO 13297 4.1 *"The hull of a metallic hull craft shall not be used as a circuit conductor"*; la excepción de 5.1 cubre sistemas de propulsión identificados como aislados]. Ver T0.1.

**Por qué el MCU va con su propio DC-DC y no con el BEC del VESC** (BOM B-DCDC): con K1 abierto el VESC solo recibe energía por R_pre (≤ V²/4R ≈ 4,8 W, §7), su BEC puede quedar en brown-out y el MCU se reiniciaría en ciclos; alimentado aguas arriba de K1, el MCU sigue vivo durante un kill, latchea el desarme, muestra el estado en el LED y vuelve a exigir 1 s en cero para re-armar.

## 2. Arquitectura de seguridad: cadena de habilitación

El motor solo puede producir torque si se cumplen **todas** a la vez:

> **Motor con torque ⇔ [F1 ∧ S1 ∧ K1 cerrado] ∧ [U3: F2 ∧ seta ∧ cordón] ∧ [Q_EN: MCU armado] ∧ [PPM válido] ∧ [comando ≠ 0]**

Barreras independientes cuando se tira del cordón (o se pulsa la seta):

| # | Barrera | Tipo | Depende de | Falla que la anula |
|---|---|---|---|---|
| 1 | K1 abre (bus sin potencia; por R_pre pasan ≤ 4,8 W [CALCULADO, §7]) | Hardware | bobina en serie con cordón/seta | K1 soldado |
| 2 | U3 deja de conducir → ADC2 alto → VESC en kill | Hardware + VESC | nodo N2, firmware VESC ≥ 6.00 (≥ 5.03 para el kill; 6.00 por LispBM) | U3 en corto, pull-up de ADC2 suelto, kill mal configurado |
| 3 | MCU ve D2/D3 en alto → desarma: PPM 1500 µs **en el mismo tick** + Q_EN abre | Software (MCU) | U1/U2, firmware P1 | U2 en corto, MCU defectuoso |
| 4 | PPM ausente → timeout del VESC → corriente de freno 0 A (rueda libre) | VESC | cable PPM, MCU | — (solo actúa si el MCU deja de mandar pulsos) |

Tiempo de corte por camino (cada uno debe cumplir el requisito por sí solo):

<!-- ELEC:corte -->
| Camino de corte (cada uno por separado) | t [ms] [CALCULADO] | Base | < 1,0 s |
|---|---|---|---|
| MCU → PPM neutro → VESC (rampa negativa) | 131 | filtro RC + 1 tick + 1 trama PPM + ramp_time_neg | ✔ |
| MCU → Q_EN abre → kill por ADC2 del VESC | 21 | filtro RC + 1 tick + sondeo de 10 ms del VESC | ✔ |
| Hardware: opto U3 apaga → kill por ADC2 (sin MCU) | 11 | sondeo 10 ms + conmutación del opto | ✔ |
| Hardware: bobina sin corriente → contactor abre | 12 | release máx. de TE Connectivity KILOVAC EV200AAANA (economizador incorporado) [VERIFICADO: hoja EV200 — release (incluye arco) máx. 12 ms @ 2000 A; close típ. 15 ms] | ✔ |
| MCU muerto: sin PPM → timeout del VESC | 250 | timeout_msec configurado | ✔ |
| MCU colgado: WDT de hardware → reset → Q_EN abre → kill ADC2 | 142 | WDTO_120MS del sketch × 1,1 [ESTIMADO: tolerancia del oscilador del WDT] + sondeo 10 ms | ✔ |

Requisito 1,0 s [VERIFICADO: inputs.yaml electrical.kill_switch_response_s_max]; peor camino individual **250 ms** [CALCULADO]. El corte real es el del camino más rápido que siga sano; el requisito se exige a cada camino por separado.
<!-- /ELEC:corte -->

## 3. Tabla de verdad del kill switch y de la cadena de habilitación

Variables: cordón (1 = clip puesto), seta (1 = liberada), desconectador S1 (1 = ON), fusibles F1/F2 (1 = sano), K1 (normal / soldado / bobina abierta), MCU armado (1 = el MCU habilita; 1 con cordón afuera modela un **MCU defectuoso**), timeout del VESC (1 = PPM perdida), falla de sensor hall. "Barreras activas" cuenta cuántas de las 4 barreras de §2 están deteniendo el motor (mín–máx sobre las combinaciones agrupadas). Modelo lógico: `calc_electronica.chain()`; lo verifica `test_truth_table_only_all_ok_runs`.

<!-- ELEC:verdad -->
| Caso | Cordón | Seta | Descon. | F1 | F2 | K1 | MCU armado | Timeout VESC | Falla sensor | Fin de carrera bucket | Motor | Límite del comando | Barreras activas (mín–máx) | Comb. |
|---|---|---|---|---|---|---|---|---|---|---|---|---|---|---|
| Todo OK, MCU armado | 1 | 1 | 1 | 1 | 1 | normal | 1 | 0 | 0 | 1 | **PUEDE GIRAR** | 100 % avance | 0–0: — | 1 |
| Todo OK, bucket abajo (o fin de carrera cortado) | 1 | 1 | 1 | 1 | 1 | normal | 1 | 0 | 0 | 0 | **PUEDE GIRAR** | ≤ reverse_limit, avance (bucket abajo) | 0–0: — | 1 |
| Cordón tirado (MCU sano → desarma) | 0 | 1 | 1 | 1 | 1 | normal | 0 | – | – | – | **PARADO** | 0 | 3–4: MCU manda neutro; VESC en kill (ADC2); VESC en timeout PPM; bus sin potencia (K1/F1/S1) | 8 |
| Cordón tirado + MCU defectuoso que sigue armado | 0 | 1 | 1 | 1 | 1 | normal | 1 | – | – | – | **PARADO** | 0 | 2–4: MCU manda neutro; VESC en kill (ADC2); VESC en timeout PPM; bus sin potencia (K1/F1/S1) | 8 |
| Cordón tirado + K1 soldado (MCU sano) | 0 | 1 | 1 | 1 | 1 | soldado | 0 | – | – | – | **PARADO** | 0 | 2–3: MCU manda neutro; VESC en kill (ADC2); VESC en timeout PPM | 8 |
| Cordón tirado + K1 soldado + MCU defectuoso | 0 | 1 | 1 | 1 | 1 | soldado | 1 | – | – | – | **PARADO** | 0 | 1–3: MCU manda neutro; VESC en kill (ADC2); VESC en timeout PPM | 8 |
| Seta pulsada (cualquier cordón/MCU/K1) | – | 0 | 1 | 1 | 1 | – | – | – | – | – | **PARADO** | 0 | 1–4: MCU manda neutro; VESC en kill (ADC2); VESC en timeout PPM; bus sin potencia (K1/F1/S1) | 96 |
| Desconectador OFF (cualquier otro estado) | – | – | 0 | – | – | – | – | – | – | – | **PARADO** | 0 | 4–4: MCU manda neutro; VESC en kill (ADC2); VESC en timeout PPM; bus sin potencia (K1/F1/S1) | 768 |
| Fusible principal F1 fundido | – | – | – | 0 | – | – | – | – | – | – | **PARADO** | 0 | 4–4: MCU manda neutro; VESC en kill (ADC2); VESC en timeout PPM; bus sin potencia (K1/F1/S1) | 768 |
| Fusible de mando F2 fundido | – | – | 1 | 1 | 0 | – | – | – | – | – | **PARADO** | 0 | 1–4: MCU manda neutro; VESC en kill (ADC2); VESC en timeout PPM; bus sin potencia (K1/F1/S1) | 192 |
| K1 con bobina abierta (no cierra) | – | – | – | – | – | bobina_abierta | – | – | – | – | **PARADO** | 0 | 1–4: MCU manda neutro; VESC en kill (ADC2); VESC en timeout PPM; bus sin potencia (K1/F1/S1) | 512 |
| K1 soldado, todo lo demás OK | 1 | 1 | 1 | 1 | 1 | soldado | 1 | 0 | 0 | – | **PUEDE GIRAR** | 100 % avance / ≤ reverse_limit, avance (bucket abajo) | 0–0: — | 2 |
| MCU desarmado (arranque, re-armado pendiente) | – | – | – | – | – | – | 0 | – | – | – | **PARADO** | 0 | 2–4: MCU manda neutro; VESC en kill (ADC2); VESC en timeout PPM; bus sin potencia (K1/F1/S1) | 768 |
| PPM perdida (timeout del VESC) | – | – | – | – | – | – | – | 1 | – | – | **PARADO** | 0 | 1–4: MCU manda neutro; VESC en kill (ADC2); VESC en timeout PPM; bus sin potencia (K1/F1/S1) | 768 |
| Falla de sensor hall | – | – | – | – | – | – | – | – | 1 | – | **PARADO** | 0 | 1–4: MCU manda neutro; VESC en kill (ADC2); VESC en timeout PPM; bus sin potencia (K1/F1/S1) | 768 |

Enumeración completa: **1536 combinaciones** en [`tabla_verdad.csv`](tabla_verdad.csv) (1 = cerrado/sano/sí, 0 = abierto/fundido/no; "–" = cualquier valor). El motor puede girar en **4** de ellas: todas exigen cordón, seta, desconectador, F1, F2, MCU armado, PPM válido y sensor sano; las variables libres son K1 (normal o soldado: un K1 soldado no se nota en marcha → se prueba antes de cada salida) y el fin de carrera del bucket, que no detiene el motor: abierto (bucket abajo o cable cortado) limita el comando a reverse_limit, siempre en avance (§5).
<!-- /ELEC:verdad -->

Lectura: (a) el cordón o la seta detienen el motor en **todas** las combinaciones, incluso con K1 soldado **y** un MCU defectuoso (queda U3 → kill del VESC); (b) con el MCU sano y K1 normal hay ≥ 3 barreras simultáneas; (c) la combinación peligrosa que la tabla **no** cubre es un **cortocircuito entre los dos conductores del cordón** (puentea el interruptor para K1 *y* para U2/U3): ver §8 y la prueba previa a cada salida.

## 4. Lista de componentes (especificación mínima)

<!-- ELEC:componentes -->
| Ref. | Componente | Especificación mínima | Elegido / referencia (BOM) | Etiqueta |
|---|---|---|---|---|
| BAT | Batería LiFePO4 de la selección | 12S, BMS ≥ 240 A cont. (total); bornes cubiertos; caja estanca elevada | 2 × LiTime 36 V 60 Ah Golf Cart en paralelo (12S2P, BMS 2 × 120 A) (B-BAT) | [CALCULADO: selección de sizing (inputs.yaml battery)] |
| F_BR | Fusible de rama (uno por batería) | 2 × 150 A, ≥ 53 V CC, poder de corte ≥ 4,4 kA (§7), a ≤ 178 mm del borne + de CADA batería | Class T Blue Sea (160 V CC, 20 kA) en portafusible Blue Sea 5007100 (110–200 A) (B-FUSE-BR, B-FUSEH-BR) | [CALCULADO: sizing.json electrical.fuse_branch_a] · 178 mm [VERIFICADO: R06 §5.1 ABYC E-11] · [VERIFICADO: Blue Sea 5113 Class T — '20,000 Ampere Interrupt Capacity (AIC)', 160 V CC máx. (fisheriessupply.com, 2026-10-02)] |
| F1 | Fusible principal (barra +) | 250 A (≥ 218,9 A), ≥ 53 V CC, poder de corte ≥ 8,8 kA (§7), junto a la barra + (protege el cable de 70 mm²) | Class T Blue Sea (160 V CC, 20 kA) en portafusible Class T con tapa (B-FUSE, B-FUSEH) | [CALCULADO: sizing.json electrical.fuse_a] · [VERIFICADO: Blue Sea 5113 Class T — '20,000 Ampere Interrupt Capacity (AIC)', 160 V CC máx. (fisheriessupply.com, 2026-10-02)] · MRBF descartado: [VERIFICADO: research/R06_electrica.md §5.4 — MRBF 10 kA @ 14 V / 5 kA @ 32 V / 2 kA @ 58 V] |
| F6 | Fusible de la toma de carga (Anderson SB50) | 32 A gPV 10×38, ≥ 1000 V CC, poder de corte ≥ 10 kA CC, en la barra +; cable ≤ 16 mm² | gPV 10×38 32 A + portafusible estanco (B-CHGFUSE) | [ESTIMADO: fusibles gPV 10×38 de 1000 V CC con poder de corte de decenas de kA (verificar en la ficha del elegido); cargador 15 A (R08a §5)] |
| S1 | Desconectador manual | ≥ 250 A cont., ≥ 44 V CC, llave removible | Biltema Hovedafbryder AFD 275 A 12–48 V (B-SW) | [VERIFICADO: R08a §3] |
| K1 | Contactor MONOestable (nunca biestable) | NA, ≥ 250 A cont., corte bajo carga ≥ 43,8 V CC; bobina de 12 V del mando (B-12V), con economizador (sin sobretensión inductiva al abrir) | KILOVAC EV200AAANA: 500 A, 12–900 V CC, bobina 9–36 V, retención 0,13 A (B-CONT) | [VERIFICADO: hoja EV200 Series (TE, 'KILOVAC EV200 Series Contactor', https://mm.digikey.com/Volume0/opasdata/d220001/medias/docus/5986/EV200_Series.pdf)] · [VERIFICADO: hoja EV200 — 500 A @ 85 °C (400 mcm); 12–900 V CC] · [VERIFICADO: https://eveurope.eu/en/product/hoofdstroomrelais-ev200-500-amp-2/ — 149,00 € ex. VAT, 54 en stock, 2026-10-02] |
| R_pre | Resistencia de precarga ∥ K1 | 100 Ω, ≥ 30 W, carcasa de Al atornillada a la base del controlador (P1-ELE-01) con disipador propio | 100 Ω 50 W carcasa de Al (B-RPRE) | [CALCULADO] [SUPUESTO: research/R06_electrica.md §3.4 (100 Ω → 5τ ≤ 1 s)] |
| ASW | Antichispa MOSFET (NO se compra) | solo arranque suave aguas abajo de K1; falla en corto → NO es seguridad; 100 A < I de batería | Flipsky Antispark Pro V3.0 (B-ASW, qty 0) | [VERIFICADO: R06 §3.1] |
| 12V | Fuente del mando y de achique | DC-DC aislado → 12 V, entrada ≥ 43,8 V y que arranque con ≤ 36,0 V (RSD-60L: 18–72 V); conectado a la barra + aguas ARRIBA de F1/S1 con su fusible F5 (removible: aislación de invierno) | Mean Well RSD-60L-12 (B-12V); NO la G (9–36 V) | [VERIFICADO: Mean Well RSD-60-SPEC (2026-07-09) — 'VOLTAGE RANGE CONTINUOUS' L: 18 ~ 72 VDC (G: 9 ~ 36 VDC: NO sirve con 12S)] · [VERIFICADO: Mean Well RSD-60-SPEC (2026-07-09) — tolerancia de salida ±2,0 %] |
| HOLD | Retención de la bobina de K1 | Schottky 3 A (1N5822) en serie + 22 mF ≥ 25 V a 12 V−, entre F2 y la seta (aguas ARRIBA de seta/cordón: no demora el corte) | 1N5822 + electrolítico (B-HOLD) | [CALCULADO, §7] · [SUPUESTO: hueco del riel de 12 V al arrancar la bomba de achique contra el límite de corriente del DC-DC (arranque < 0,1 s × 2,5); lo valida T0.4] |
| F2 | Fusible de mando (bobina K1, salida 12 V) | 5 A lento, portafusible en línea estanco | B-CFUSE | [CALCULADO: ≥ 1,25 × cierre 3,8 A] |
| F3 | Fusible del DC-DC 5 V (entrada, lado batería) | 1 A, ≥ 58 V CC, portafusible en línea | B-CFUSE | [SUPUESTO: protege el cable de 0,5 mm²; consumo de entrada ≈ 10 mA [ESTIMADO: 0,3 W / 38,4 V / 0,8]] |
| F5 | Fusible de entrada de B-12V (lado batería) | 3 A, ≥ 58 V CC, portafusible en línea | B-CFUSE | [ESTIMADO: 60 W / 36 V / 0,85 ≈ 2 A de entrada a plena carga → 3 A] |
| CORDÓN | Interruptor de hombre al agua | contacto CERRADO con clip (fail-safe), ≥ 3,8 A de cierre a 12 V CC | Watski Dødmands kontakt universal, polos M (B-KILL); alt. Sea Dog SD-420487-1 | [VERIFICADO: research/R08a §3 — Watski 'Dødmands kontakt universal' 12 V – 15 A] — ✔ cumple en el mando de 12 V · Sea Dog 5 A [VERIFICADO: Sea Dog SD-420487-1, 5 A máx. (research/R06_electrica.md §3.2)] |
| SETA | Seta de emergencia | NC, enclavamiento (girar para rearmar), Ø22, IP65, ≥ 5 A a 12 V CC | B-ESTOP | [ESTIMADO: especificación de BOM] |
| J1 | Conector IP68 del hall (caña) | 4 polos apantallado: 5 V, GND, OUT, malla | Lumberg 0332-04 + 0322-04 (B-SIGNAL) | [VERIFICADO: R08a §8] |
| J2 | Conector IP68 del cordón (caña) | 2 polos, ≥ 5 A | Cliffcon 68 FM686812 (B-KCONN) | [VERIFICADO: R08a §8] |
| ESC | VESC de la selección | FW ≥ 6.00 (LispBM; de fábrica 5.02 → flashear en T0.0), l_current_max 292 A, entradas PPM, ADC1 y ADC2 accesibles; caja de agua en el circuito de refrigeración | Flipsky FSESC 75350 con caja de agua (VESC, filtro de fase, IP65) (B-ESC) — sobre base elevada P1-ELE-01 + capota P1-ELE-02 | [VERIFICADO: research/R11 §2] · FW de fábrica [inputs.yaml esc.options, allí VERIFICADO] |
| M | Motor | sensor de temperatura del bobinado leído por el VESC; sensor hall | Maytech MTI120116 150 KV (inrunner refrigerado por agua, 10–16S), variante CON hall (B-MOT); NTC10K 3950 de fábrica (cable amarillo) → TEMP del VESC | [VERIFICADO: página Maytech MTI120116 — 'Yellow: Temp Sensor (NTC10K 3950k)'; R06 §1.2 soporte NTC 10 k en el VESC] |
| IMD | Monitor de aislamiento | solo clase 72 V (sistema flotante > 50 V CC) | no requerido (≤ 50 V CC) | [VERIFICADO: research/R11 §8; R10b H8] |
| DC-DC | Regulador → 5 V (MCU) | 5 V ≥ 0,5 A; entrada máx. > l_max_vin = 53 V; alimentado aguas abajo de S1 y aguas ARRIBA de K1 | RECOM R-78HB5.0-0.5 9–72 V (B-DCDC) | [VERIFICADO: research/R08a §9 — TRACO TSR 1-2450E, entrada 7–36 V → 5 V 1 A] · [VERIFICADO: research/R08a §9 — RECOM R-78HB5.0-0.5, entrada 9–72 V → 5 V 0,5 A] |
| MCU | Arduino Nano (ATmega328P, 5 V, 16 MHz) | bootloader NUEVO (Optiboot): el viejo entra en bucle tras un reset por WDT | Arduino Nano V3 (B-MCU) | [VERIFICADO: R08a §9] · bootloader [ESTIMADO: problema conocido; se prueba en T0.18] |
| HALL | Sensor hall lineal ratiométrico 5 V + imán | salida analógica ratiométrica; imán NdFeB Ø10×3 diametral | Allegro A1324 (B-HALL) | [VERIFICADO: R08a §9 (sensor)]; imán [ESTIMADO] |
| U1–U3 | Optoacoplador de fototransistor (×3) | CTR ≥ 50 % a 5 mA, Vceo ≥ 30 V, aislación ≥ 2,5 kV | genérico 4 pines (B-PCB) | [SUPUESTO: especificación mínima de compra CTR ≥ 50 %] |
| D_U1–D_U3 | Diodo antiparalelo de cada LED de opto | 1N4148 o similar (≥ 75 V, ≥ 100 mA), cátodo al ánodo del LED (con el EV200 N2 no baja de 0 V; queda como protección ante un K1 de reemplazo sin economizador) | genérico (B-PCB) | [CALCULADO, §7] |
| R1 / R2 | R serie de los LED de U1 / U2+U3 (mando de 12 V) | 1,8 kΩ / 1,8 kΩ, 0,25 W | genéricas (B-PCB) | [CALCULADO] |
| Q_EN | Transistor de habilitación (ADC2 del VESC) | NPN Vceo ≥ 30 V, Ic ≥ 50 mA; base 1 kΩ desde D4 y 10 kΩ a GND | genérico | [SUPUESTO] |
| Pasivos | Pull-ups y filtros | D2/D3: 10 kΩ a 5 V + 100 nF; ADC2: 10 kΩ a 3,3 V; A0: 1 kΩ + 100 nF + 100 kΩ a GND; PPM: 10 kΩ a GND | genéricos | [SUPUESTO: pull-up externo 10 kΩ (D2/D3 a 5 V; ADC2 a 3,3 V, R06 §2.5)] · [SUPUESTO: 10 kΩ × 100 nF en D2/D3 (inmunidad a ruido del motor)] |
| LED | LED de estado de panel | IP67, 5 V con resistencia | genérico | [SUPUESTO] |
| Cables | Potencia / fases / mando / señal | DC 70 mm² (barras–F1–S1–K1–ESC) y 35 mm² de rama (estañados); fases: cables PROPIOS del motor (6 AWG × 300 mm) y del ESC (8 AWG) unidos con conectores bala 8 mm (sin tramo de 95 mm²: el calibre lo fijan esos cables; caída 1,48 %); mando 0,75–1 mm² estañado; hall: 4 × 0,25 mm² apantallado redondo; cordón: 2 × 0,75 mm² redondo | Skyllermarks estañado (B-CAB-DC, B-CAB-PAR); B-PHCON; B-LUG10 (cables 8 AWG del ESC a terminales M8) | [CALCULADO: sizing.json cables; §7 caída de fases] · mando/señal [SUPUESTO] |
| Prensaestopas | Pasamuros IP68 | caja de batería: un cable REDONDO por prensaestopas, M32 para 70 mm² [ESTIMADO: Ø ext ≈ 17 mm]; M16 4–8 mm (hall, cordón) en la consola | M32 (B-GLAND32) / Biltema M16 (B-GLAND16) | [VERIFICADO: R08a §8] · regla de un cable [ESTIMADO: R05 §B8] |
<!-- /ELEC:componentes -->

## 5. Firmware

Firmware v2.0 del waterjet. **La marcha atrás es el BUCKET** (palanca + cable Mach5, enclavamiento mecánico con el acelerador, `04_diseno/piezas/_ctl.py`): el motor gira **siempre en avance** y con el bucket abajo el comando se limita a `reverse_limit`. El único giro inverso es la **limpieza de rejilla** (pulsador dedicado, lento y por tiempo limitado). [NO EJECUTADO en hardware]; lógica verificada en PC (§5.8).

### 5.1 Estructura

- `throttle_logic.c/.h`: función de paso `tl_outputs_t tl_tick(tl_ctx_t *s, const tl_inputs_t *in, uint32_t dt_ms)`. Entradas: ADC 10 bits del hall A1324 de la palanca del acelerador (ratiométrico, Vref = AVCC = alimentación del sensor), `kill_cord_ok`, `estop_ok`, `vesc_ok` (opcional), `bucket_up` (fin de carrera), `sel_open` (selector de perfil), `weed_btn` (pulsador de rejilla), `dt_ms`. Salidas: `cmd` ∈ [−`weed_cmd`, 1], `ppm_us` ∈ [1000, 2000] (1500 = neutro), `state`, `flags` (32 bits), `enable`, `profile`. Sin dependencias de Arduino; solo tipos de ancho fijo y `float` (en AVR `double` = `float`). Auxiliares puros: `tl_position`, `tl_shape` (zona muerta + expo, con signo), `tl_thrust` (objetivo ≥ 0 según lado de la palanca y bucket), `tl_cmd_to_ppm`.
- `p1_throttle.ino`: lee entradas cada 10 ms [SUPUESTO], llama `tl_tick`, aplica salidas; las ISR de INT0/INT1 (D2/D3) ponen neutro y abren Q_EN **dentro de ~1 ms** del flanco a kill [ESTIMADO: 0,92 τ hasta V_IH = 0,6·Vcc con τ = 10 kΩ × 100 nF = 1 ms], antes del próximo tick. El neutro del PPM entra en la **próxima trama** (OCR1A con doble buffer: ≤ 20 ms); Q_EN abre en el acto.

### 5.2 Máquina de estados y reglas

| Estado | Salida | Entra cuando | Sale cuando |
|---|---|---|---|
| `DISARMED` | neutro, `enable` = 0, perfil COSTA | power-on; cordón/seta abiertos; watchdog lógico | ≥ `arm_hold_ms` continuos con cordón+seta OK, sensor y calibración válidos y acelerador en zona muerta → `ARMED` |
| `FAULT` | neutro, `enable` = 0 | ADC < `adc_fault_low` o > `adc_fault_high`; salto imposible; VESC en falla (si se usa); calibración/config inválida | igual que `DISARMED` (re-armado con 1 s en cero) |
| `ARMED` | 0, `enable` = 1 | armado, acelerador en zona muerta, sin dwell pendiente | comando ≠ 0 |
| `RUN_FWD` | rampa hacia el objetivo, ≤ 100 % | comando > 0 con el bucket ARRIBA | soltar → `DWELL_ZERO`; falla → `DISARMED`/`FAULT` en el **mismo tick** |
| `RUN_REV` | rampa, **en avance**, ≤ `reverse_limit` | comando > 0 con el bucket ABAJO (marcha atrás por el bucket) | ídem |
| `WEED` | −`weed_cmd` (giro inverso) | limpieza de rejilla (abajo) | soltar el pulsador, mover el acelerador o `weed_max_ms` → 0 inmediato |
| `DWELL_ZERO` | 0 | la salida llegó a 0 tras girar; o se pidió el sentido opuesto | `dwell_ms` cumplido; mismo sentido → sigue sin esperar |

Reglas:
1. **Armado**: solo con el acelerador en cero ≥ 1 s continuo y todo OK; cualquier kill/fault/watchdog **latchea** el desarme (aunque el cordón vuelva, no arranca hasta 1 s continuo en cero); un `dt_ms` > `watchdog_ms` (lazo colgado, timeout de señal) corta y no cuenta como tiempo en cero. Kill, seta y contactor sin cambios respecto de v1.
2. **Sensor**: fuera de banda (abierto/corto) o salto imposible → neutro + `FAULT` en el mismo tick. Todo corte de seguridad es **inmediato** (sin rampa); la subida tiene rampa (0→100 % en ≥ `ramp_up_ms`) y la bajada es rápida (`ramp_down_ms`).
3. **Bucket** (fin de carrera NC en D5: cerrado = ARRIBA; abierto = ABAJO **o cable cortado**): con el bucket ABAJO el objetivo es `|forma(pos)| × reverse_limit`, siempre ≥ 0 (motor en avance), sea cual sea el lado de la palanca. Pasar a ABAJO es inmediato; pasar a ARRIBA exige `sw_debounce_ms` de contacto cerrado continuo (un rebote no habilita el 100 %). Si el bucket baja mientras la salida todavía baja por rampa, se recorta a `reverse_limit` en el acto.
4. **Cambio de bucket con el acelerador fuera de cero** (el enclavamiento mecánico lo impide: indica falla de cable/fin de carrera o el bucket llegando tarde): salida 0 **en ese tick** y retenida (`BKT_HOLD`, `enable` sigue en 1) hasta que el acelerador vuelve a la zona muerta. Esperar el clic del fin de carrera antes de acelerar tras subir el bucket.
5. **Incoherencias palanca/fin de carrera** (`BKT_MISM`): palanca del lado de reversa con el fin de carrera en ARRIBA → **salida 0** (si el enclavamiento se rompió el bucket está arriba y el bote iría hacia adelante); palanca de avance con el fin de carrera abierto → limitado a `reverse_limit` (caso típico: cable cortado → se vuelve a puerto con potencia reducida).
6. **Nunca se invierte el giro** salvo la **limpieza de rejilla**: pulsador D8 sostenido ≥ `weed_hold_ms` (un golpe o rebote no la inicia), soltado al menos una vez desde el armado (un pulsador en corto no hace nada), acelerador en cero y salida en 0 ≥ `dwell_ms` (impulsor frenado). Comando −`weed_cmd`; la **velocidad** inversa la topea el VESC con `l_min_erpm` (§6, ≈ 25 % de las rpm de 5 kn). Termina en el acto al soltar el pulsador, al mover el acelerador o a los `weed_max_ms` (≤ 3 s; `tl_config_check` rechaza más de 3000 ms o `weed_cmd` > 0,25); para repetir hay que soltar y volver a apretar. Tras la limpieza el avance exige `dwell_ms` en cero.
7. **Perfil** (selector D7: a GND = ABIERTO; abierto/cortado = COSTA): arranca **siempre en COSTA (5 kn)** al encender y en cada armado, aunque el selector esté en ABIERTO; ABIERTO se toma solo si el selector pasó por COSTA después del armado **y** con la salida en 0 y el acelerador en cero (`PROF_WAIT` mientras tanto). Volver a COSTA es inmediato (tras el antirrebote), también en marcha. Desarmado = COSTA.

Flags (`tl_outputs_t.flags`, bits en `throttle_logic.h`): `KILL_CORD`, `ESTOP`, `SENS_LOW`, `SENS_HIGH`, `SENS_JUMP`, `WATCHDOG`, `VESC` (latcheados hasta el próximo armado); `CAL`, `NOT_ZERO`, `RAMP`, `BKT_LIM`, `DWELL`, `ARMING`, `BKT_DOWN`, `BKT_HOLD`, `BKT_MISM`, `WEED`, `WEED_WAIT`, `PROF_OPEN`, `PROF_WAIT` (instantáneos).

### 5.3 Parámetros por defecto (leídos de `tl_default_config()`)

<!-- ELEC:firmware -->
| Parámetro (`tl_config_t`) | Valor por defecto | Etiqueta |
|---|---|---|
| `deadband` | 0,08 | [SUPUESTO: ±8 % de la semicarrera (pedido de diseño); ajustar en T0] |
| `expo` | 0,0 | [SUPUESTO: lineal; la rampa ya suaviza. 0,3 si la palanca resulta "nerviosa"] |
| `reverse_limit` | 0,63 | [CALCULADO: calc_electronica reverse_current_frac = waterjet.reverse.power_limit_frac 0,5^(2/3) (bomba P ∝ T^1,5)] |
| `jump_travel_per_s` | 25,0 | [SUPUESTO: la palanca no recorre tope a tope en < 40 ms; validar en T0.9] |
| `weed_cmd` | 0,10 | [SUPUESTO: 10 % de l_current_max en giro inverso, solo para soltar algas; la velocidad la topea el VESC con l_min_erpm] |
| `adc_rev` | 1,30 V → 266 cuentas | [ESTIMADO: provisorio A1324 2,5 V en reposo con imán diametral; lo reemplaza la calibración (T0.5)] |
| `adc_center` | 2,50 V → 512 cuentas | [ESTIMADO: provisorio A1324 2,5 V en reposo con imán diametral; lo reemplaza la calibración (T0.5)] |
| `adc_fwd` | 3,70 V → 757 cuentas | [ESTIMADO: provisorio A1324 2,5 V en reposo con imán diametral; lo reemplaza la calibración (T0.5)] |
| `adc_fault_low` | 0,30 V → 61 cuentas | [SUPUESTO: ~0,3 V (pedido de diseño)] |
| `adc_fault_high` | 4,70 V → 962 cuentas | [SUPUESTO: ~4,7 V (pedido de diseño)] |
| `min_half_span` | 0,50 V → 102 cuentas | [SUPUESTO: semicarrera >= 0,5 V -> >= 102 cuentas de resolución] |
| `jump_noise_counts` | 12 | [ESTIMADO: ruido hall+ADC tras promediar 4 muestras ~±5 cuentas, ×2] |
| `arm_hold_ms` | 1000 | [SUPUESTO: >= 1 s en cero para armar (pedido de diseño)] |
| `ramp_up_ms` | 1000 | [SUPUESTO: 0->100 % en >= 1 s (pedido de diseño; R06 §2.6 sugiere ~1 s)] |
| `ramp_down_ms` | 250 | [SUPUESTO: bajada rápida 100->0 % en 0,25 s; los cortes de seguridad son inmediatos] |
| `dwell_ms` | 500 | [SUPUESTO: >= 0,5 s en cero antes de girar al revés (el impulsor se frena en el agua)] |
| `watchdog_ms` | 100 | [SUPUESTO: tick nominal 10 ms; > 100 ms sin tick = lazo colgado] |
| `ppm_min_us` | 1000 | [VERIFICADO: VESC appconf_default.h APPCONF_PPM_PULSE_START 1,0 ms] |
| `ppm_center_us` | 1500 | [VERIFICADO: APPCONF_PPM_PULSE_CENTER 1,5 ms] |
| `ppm_max_us` | 2000 | [VERIFICADO: APPCONF_PPM_PULSE_END 2,0 ms] |
| `weed_max_ms` | 3000 | [SUPUESTO: limpieza de rejilla <= 3 s por pulsación (pedido de diseño)] |
| `weed_hold_ms` | 300 | [SUPUESTO: pulsación sostenida 0,3 s: un golpe o un rebote no la inicia] |
| `sw_debounce_ms` | 50 | [SUPUESTO: antirrebote del fin de carrera (solo hacia ARRIBA) y del selector] |
| `cal_valid` | 0 | — |
| `use_vesc_ok` | 0 | [SUPUESTO: sin telemetría UART en P1; hook para P2] |
<!-- /ELEC:firmware -->

`reverse_limit` = 0,63 sale de `calc_electronica.py` (`vesc_values.reverse_current_frac` = `waterjet.reverse.power_limit_frac`^(2/3), bomba P ∝ T^1,5); `test_defaults_match_requirements` exige que coincidan. Detección de "salto imposible": entre dos muestras se admite `jump_noise_counts + |adc_fwd − adc_rev| × jump_travel_per_s × dt` [CALCULADO: ≈ 135 cuentas en 10 ms = 27 % de la carrera total]. Una palanca a mano (0→100 % en 150 ms) o el retorno por resortes en 30 ms no disparan; un salto centro→tope en un tick sí (tests).

### 5.4 Pines del Nano

| Pin | Función | Hardware | Falla → resultado |
|---|---|---|---|
| A0 | Hall A1324 de la palanca del acelerador (ADC, Vref AVCC 5 V) | 1 kΩ + 100 nF; 100 kΩ a GND | señal o 5 V cortados → ≈ 0 V → `SENS_LOW` |
| D2 (INT0) | Cordón (opto U2) | `INPUT_PULLUP` + 10 kΩ externo + 100 nF | ALTO = kill (abierto/cortado/suelto) |
| D3 (INT1) | Seta (opto U1) | ídem | ALTO = e-stop |
| D5 | Fin de carrera del bucket, NC a GND | `INPUT_PULLUP` + 10 kΩ externo [SUPUESTO] | cable cortado → ALTO = bucket ABAJO → comando ≤ `reverse_limit` (fail-safe) |
| D7 | Selector de perfil a GND | `INPUT_PULLUP` | cable cortado → COSTA |
| D8 | Pulsador de limpieza de rejilla NA a GND | `INPUT_PULLUP` | cortado → sin limpieza; en corto → ignorado (exige soltar) |
| D9 (OC1A) | PPM, Timer1 modo 14, prescaler 8, 50 Hz | 10 kΩ a GND en el VESC | reset del MCU → sin pulsos → timeout del VESC |
| D4 | Q_EN (habilita ADC2 a GND) | NPN, base 1 kΩ, 10 kΩ a GND | reset → transistor abierto → kill del VESC |
| D12 | Perfil al VESC: ALTO = ABIERTO | 10 kΩ a GND [SUPUESTO] | reset/cortado → BAJO = COSTA |
| D6 / D13 | LED de estado | panel IP67 | — |

D10 queda libre a propósito (OC1B del Timer1 del PPM).

**Perfil en el VESC (`firmware/vesc_perfil.lisp`, LispBM, FW ≥ 6.00).** D12 → 10 kΩ → ADC1 del conector COMM del VESC, 20 kΩ de ADC1 a GND (5 V × 20/30 ≈ 3,3 V; las entradas ADC del VESC son de 3,3 V [ESTIMADO: verificar en la hoja del FSESC 75350]). El script lee `(get-adc 0)` cada 50 ms y hace `(conf-set 'l-max-erpm …)`: COSTA apenas la línea cae (una muestra), ABIERTO tras 4 muestras seguidas en ALTO; al arrancar fija COSTA. `conf-set` no escribe la flash, así que la configuración **guardada** del VESC queda en COSTA (§6) y si el script no corre, el cable se corta o el MCU se reinicia, el bote queda en 5 kn. Las API (`get-adc`, `conf-set`, `'l-max-erpm`, `loopwhile`, `sleep`) [VERIFICADO: vedderb/bldc master `lispBM/README.md`, leído 2026-10-01] y la sintaxis (`if` con else, `and`, `{ }` = `progn`) [VERIFICADO: svenssonjoel/lispBM `doc/lbmref.md`]. Los topes de ERPM son los de `electronica.json` (`vesc_values.l_max_erpm` / `erpm_tech`) y **no se escriben a mano**: `calc_electronica.py` reescribe las dos líneas `(define erpm-costa …)` / `(define erpm-abierto …)` del script (y `--check` falla si quedaron viejas); `test_vesc_profile_lisp_matches_electronica_json` lo vuelve a verificar. ERPM = rpm × pares de polos: con el MTI120116 son **5 pares** (12N/10P [VERIFICADO: página Maytech]), no 2 como se había supuesto; contar los imanes al recibir el motor (T0.6). El tope COSTA hace cumplir **solo los 5 kn** de la franja de 300 m (piloto liviano, banda baja, batería llena: sizing `legal_speed`); los 4 kn de Sønderborg Havn (Als Sund) y los 3 kn de las marinas (R13 §3) **no** los limita el firmware: los respeta el piloto con el acelerador.

Carga con VESC Tool [ESTIMADO: verificar en VESC Tool — nombres de menú de VESC Tool 6.x no verificados en esta sesión]: conectar por USB → *VESC Dev Tools → LispBM* → abrir `vesc_perfil.lisp` → *Upload* (lo guarda en la flash del VESC y lo ejecuta en cada arranque) → en la consola/REPL de LispBM verificar con `(conf-get 'l-max-erpm)`: COSTA con D12 bajo, ABIERTO con D12 alto (T0.20). Antes, en *App Settings → General*, comprobar que ADC1 no lo use ninguna app (app PPM sola) y en *Realtime Data* que ADC1 siga a D12 [ESTIMADO: verificar en VESC Tool].

Coherencia del cableado en serie: si D2 dice "cordón OK" pero D3 dice "seta abierta" (imposible con la serie seta→cordón), el sketch trata ambos como abiertos. WDT de hardware `WDTO_120MS`; `wdt_reset()` solo tras un tick completo; el registro de reset (MCUSR) se imprime al arrancar (bit 0x08 = reset por WDT; con Optiboot puede leer 0 [ESTIMADO]). `p1_early_init()` (en `.init3`: copia MCUSR y apaga el WDT antes de `setup()`) lleva `__attribute__((used))`: el core compila con `-flto` y sin `used` el enlazador la descarta (sin Optiboot, tras un reset por WDT el WDT seguiría activo a 16 ms → bucle de reset). Lo verifica `test_avr_build_if_toolchain_available` con `avr-objdump`.

### 5.5 Compilación

```
arduino-cli core install arduino:avr
arduino-cli compile --fqbn arduino:avr:nano 04_diseno/electronica/firmware/p1_throttle
# para T0 (habilita el comando 'h' que cuelga el lazo para probar el WDT):
arduino-cli compile --fqbn arduino:avr:nano --build-property "compiler.cpp.extra_flags=-DP1_TEST_COMMANDS=1" 04_diseno/electronica/firmware/p1_throttle
arduino-cli upload  --fqbn arduino:avr:nano -p /dev/ttyUSB0 04_diseno/electronica/firmware/p1_throttle
```

v2.0 **no se compiló para AVR** (en esta máquina no hay `avr-gcc` ni `arduino-cli`; el test correspondiente se salta; compilarlo es el primer paso de T0.0): la lógica compila con gcc en C99 estricto con `-Wconversion -Werror`. Ojo AVR: los flags son `uint32_t` y los menores a 0x10000 son `unsigned int` de 16 bits → negarlos siempre como `~(uint32_t)TL_F_x`. Si se modifica la lógica: `cp firmware/throttle_logic.[ch] firmware/p1_throttle/src/` (el test lo exige). FQBN `arduino:avr:nano` = bootloader nuevo; con un clon de bootloader viejo, regrabar el bootloader o comprobar T0.18.

### 5.6 Calibración (una vez, y tras cambiar imán/sensor)

Monitor serie 115200. Con **el cordón afuera** (K1 abierto; el sketch se niega a calibrar con el cordón puesto): `c` → soltar la palanca, `1` → tope avance, `2` → **bajar el bucket** (el enclavamiento solo deja ir al lado de reversa con el bucket abajo) y llevar a tope atrás, `3` → `s`. `tl_calibrate()` exige orden monótono, semicarrera ≥ 102 cuentas y los tres puntos dentro de la banda válida; se guarda en EEPROM con CRC-8. Sin calibración válida el estado es `FAULT` permanente (no arma). Se admite el imán invertido.

### 5.7 LED y telemetría

LED: fijo = armado; parpadeo corto (2 de cada 3 × 100 ms) = limpieza de rejilla; 4 Hz = desarmado con acelerador fuera de cero; 2 Hz = contando 1 s en cero; destello cada 2 s = cordón/seta abiertos; 10 Hz = `FAULT`. Telemetría CSV cada 100 ms (`t` la activa/desactiva): `t_ms, estado, adc, cmd, ppm_us, flags, enable, perfil` (bucket abajo = bit 0x2000 de `flags`) — es el registro que usa T0.

### 5.8 Tests (`pytest -q tests/test_firmware.py`)

Compila `throttle_logic.c` con `gcc -std=c99 -Wall -Wextra -Wpedantic -Wconversion -Wshadow -Wdouble-promotion -Werror` a una librería compartida y la ejecuta desde Python por ctypes, tick a tick (el tamaño de cada struct se verifica contra C; el tick se lee de `TICK_MS` del sketch; movimientos de palanca realistas). Escenarios: defaults vs requisitos, `inputs.yaml` y `calc_electronica` (`reverse_limit` = 0,63, `l_min_erpm`); config insegura rechazada (limpieza > 3 s, `weed_cmd` > 0,25…); sin calibración no arma; **arranque con acelerador ≠ 0 no arma** (incl. bucket abajo); armado tras 1 s continuo en cero; rampa de subida y bajada rápida; cordón/seta → neutro en el mismo tick + latch; **bucket abajo limita** a `reverse_limit` siempre en avance (y con el fin de carrera cortado desde el encendido); lado de reversa con bucket arriba → 0; **nunca negativo sin el pulsador**; bucket hacia abajo inmediato / hacia arriba con antirrebote; **cambio de bucket con acelerador > 0 → salida 0 hasta volver a cero** (3 casos); cambio con acelerador en 0 sin retención; recorte al bajar el bucket durante la rampa; **limpieza de rejilla**: lenta, ≤ `weed_cmd`, ≤ 3 s aunque se sostenga, una por pulsación, corte al soltar o mover el acelerador, exige acelerador en 0 y motor parado ≥ dwell, ignora pulsaciones cortas/rebotes y un pulsador apretado al armar, no arranca con la palanca fuera de cero aunque la salida sea 0, la corta el kill; **perfil COSTA por defecto** al encender y en cada re-armado (aunque el selector esté en abierto), ABIERTO solo pasando por costa y con salida 0, vuelta a costa inmediata; **sensor fuera de rango** (6 valores, también durante limpieza y con bucket abajo) → neutro + `FAULT`; salto imposible vs mano real; **watchdog/timeout** (100 ms pasa, 101 ms corta); zona muerta y `tl_thrust`; expo; calibración; falla del VESC; tiempo de corte < 1 s; **fuzz** de 30 000 ticks con invariantes (PPM en rango, neutro ante condición insegura, comando ≥ −`weed_cmd` y negativo solo en limpieza con pulsador sostenido ≥ `weed_hold_ms` y acelerador en 0, ≤ 3 s, bucket abierto ⇒ ≤ `reverse_limit`, rampa, dwell entre signos, perfil abierto solo armado y desde salida 0, cada armado en COSTA y tras ≥ 1 s en cero); **tabla de verdad** (1536 filas, ahora con el fin de carrera del bucket) y sus filas que giran contrastadas contra la lógica; copia del sketch idéntica, pines requeridos y sin repetir; `vesc_perfil.lisp` coherente con `electronica.json`; config VESC coherente con sizing; archivos generados vigentes. Una prueba de mutación (11 alteraciones de la lógica: sin retención por bucket, limpieza sin tope de tiempo / sin acelerador en 0 / sin dwell, reversa negativa, avance sin límite con bucket abajo, perfil sin pasar por costa / sin salida 0, sin antirrebote, sin recorte, pulsador sin soltar) fue detectada en los 11 casos. Resultado: **69 passed, 1 skipped** (la compilación AVR se salta sin `avr-gcc`/`arduino-cli`).

## 6. Configuración obligatoria del VESC

Los valores por defecto del firmware **no sirven** para el bote [VERIFICADO: R06 §2.4]. Cargar en VESC Tool (Motor Config y App Config), escribir, reiniciar, **volver a leer** y comparar con esta tabla (T0.6). Guardar el XML exportado junto a este README. Columna "Default FW": [VERIFICADO: `motor/mcconf_default.h` y `applications/appconf_default.h` de vedderb/bldc, rama master, leídos el 2026-10-01]; entre paréntesis, el valor que pone el firmware del **target 75_100** (`hwconf/flipsky/hw_75_100.h`) cuando difiere [VERIFICADO: R06 §2.2, §2.4] — es lo que se verá en VESC Tool con un Flipsky 75100; los nombres de parámetro, [VERIFICADO: `datatypes.h`].

<!-- ELEC:vesc -->
| Grupo | Parámetro (VESC Tool) | Valor P1 | Unidad | Default FW | Etiqueta | Nota |
|---|---|---|---|---|---|---|
| Firmware | `versión de firmware` | ≥ 6.00 | — | 5.02 | [VERIFICADO: research/R06_electrica.md §2.2 — KILL_SW_MODE aparece en 5.03] · ≥ 6.00 por LispBM (vesc_perfil.lisp) [VERIFICADO: vedderb/bldc lispBM/README.md, FW 6.00+] · de fábrica 5.02 [inputs.yaml esc.options.FSESC75350.fw_factory, allí VERIFICADO] | FLASHEAR antes de configurar (T0.0): con el FW de fábrica no hay LispBM y el perfil COSTA/ABIERTO no funciona |
| Firmware | `foc_phase_filter_enable` | true (dejar) | — | true (false en target 75_100, FW ≥ 6.00) | [VERIFICADO: research/R06_electrica.md §2.1 — Flipsky: con FW ≥ 5.3 apagar el filtro de fase o se daña el 75100]; default [VERIFICADO: mcconf_default.h MCCONF_FOC_PHASE_FILTER_ENABLE; hw_75_100.h false (research/R06_electrica.md §2.2)] | Solo Flipsky 75100/75200 sin filtro; el FSESC 75350 y el 110300 SÍ tienen filtro de fase (research/R11 §2) |
| Motor | `si_motor_poles` | 10 | — | 14 | [inputs.yaml motor.options.MTI120116_150.pole_pairs = 5 (allí con su etiqueta)] · default FW 14 [VERIFICADO: mcconf_default.h MCCONF_SI_MOTOR_POLES]; CONTAR imanes del motor real | — |
| Motor | `l_current_max` | 292 | A | 60 | [CALCULADO: sizing.json electrical.I_phase_limit_A = 292 A: par T_max 18,6 N·m < par de corte del pasador / 1,8] · default 60 A [VERIFICADO: mcconf_default.h] | Límite de FASE: fija el par máx. (el pasador de corte no corta en arranques). En PPM Current acelera con servo × l_current_max [VERIFICADO: app_ppm.c] |
| Motor | `l_current_min` | -87,6 | A | -60 | [CALCULADO: −0,3 × l_current_max] · [SUPUESTO: corriente de frenado = 30 % de l_current_max (un jet casi no regenera; protege BMS)] | Corriente de FRENADO (servo opuesto a las rpm) [VERIFICADO: app_ppm.c] |
| Motor | `límite de potencia en REVERSA (bucket abajo, MCU)` | P ≤ 0,5 × P → corriente ≤ 0,63 × l_current_max = 184 | A | — | [CALCULADO: inputs.yaml waterjet.reverse.power_limit_frac 0,5; [CALCULADO: bomba con T ∝ n², P ∝ n³ → P ∝ T^1,5; límite de par = P_frac^(2/3)]] | El jet NO invierte el giro: la reversa es el bucket. El MCU lee el fin de carrera del bucket y topea el PPM (reverse_limit del firmware = este valor; fin de carrera en D5, README §5) |
| Batería | `l_in_current_max` | 192 | A | 99 (100 en target 75_100) | [CALCULADO: ⌈1,05 × I_bat pico 192 A⌉ a 5 A, ≤ mín(80 % × BMS 240 A = 192 A; BMS de rama 120 A / reparto 0,6 = 200 A)] · reparto [inputs.yaml electrical.parallel_share_max, allí SUPUESTO] | LIMITA la V máx: I_bat pico de sizing > límite. Con 2 baterías en paralelo y reparto 60/40 la rama más cargada lleva 115 A = 96 % de su BMS (120 A): no supera el BMS, pero el margen del 80 % solo vale con reparto parejo. Medir el reparto en T1 (pinza en cada rama) |
| Batería | `l_in_current_min` | -10 | A | -60 (-100 en target 75_100) | [SUPUESTO: la hélice regenera poco; protege el BMS al frenar/invertir] · defaults [VERIFICADO: mcconf_default.h; hw_75_100.h (research/R06_electrica.md §2.4)] | — |
| Batería | `l_battery_cut_start` | 36 | V | 10 | [CALCULADO: 12 celdas × 3 V] · [ESTIMADO: research/R06_electrica.md §2.4, corte LFP 3,0 V/celda] | — |
| Batería | `l_battery_cut_end` | 33,6 | V | 8 | [CALCULADO: 12 × 2,8 V] · [ESTIMADO: research/R06_electrica.md §2.4, corte LFP 2,8 V/celda] | — |
| Batería | `l_max_vin` | 53 | V | 57 (90 en target 75_100) | [CALCULADO: 1,2 × 43,8 V] · [SUPUESTO: l_max_vin = 1,2 × V carga plena → protege el DC-DC ante un BMS abierto regenerando] | OJO: ≥ entrada máx. del DC-DC → usar R-78HB (72 V) |
| Velocidad | `l_max_erpm` | 9200 | ERPM | 100000 | [CALCULADO: tope legal 'modo costa' = rpm a 5 kn con carga liviana (sizing.legal_speed, D-30); techo técnico 24000 = 1,15 × 4182 rpm × 5 pares de polos] | Sin carga (hélice fuera del agua) el motor iría a 6570 rpm = 32850 ERPM [CALCULADO: KV 150 × 43,8 V]; el límite lo baja a 1840 rpm. ERPM = rpm × 5 pares de polos [inputs.yaml motor.options.MTI120116_150.pole_pairs] |
| Velocidad | `l_max_erpm (perfil 2: fuera de la franja de 300 m)` | 24000 | ERPM | 100000 | [CALCULADO: 1,15 × 4182 rpm (n máx. de sizing) × 5 pares de polos] | Perfil ABIERTO (vesc_perfil.lisp, en RAM); por defecto arranca SIEMPRE en COSTA (5 kn, R13). ✔ 4800 rpm > 4369 rpm a fondo con batería llena [CALCULADO: 4182 × (43,8/38,4)^(1/3)] — el tope no recorta la V máx. |
| Velocidad | `tope de cavitación (NO se programa)` | 20200 | ERPM | — | [CALCULADO: sizing.cavitation_cap — 4048 rpm con S ≤ 3.5 a punto fijo × 5 pares de polos] | A punto fijo el límite de corriente ya deja el impulsor en S ≈ 3.5 (sizing); a velocidad la inmersión y la presión de toma suben y S baja. Un tope fijo de ERPM recortaría la V máx. por ratos a 26.0 km/h, por eso no se programa: verificar en T2 (sin ruido de cavitación a punto fijo) |
| Velocidad | `l_min_erpm` | -3100 | ERPM | -100000 | [CALCULADO: −626 rpm × 5 pares de polos] · [SUPUESTO: giro inverso lento (≤ 25 % de las rpm de 5 kn) solo para soltar algas de la rejilla] | Solo giro inverso lento para limpiar la rejilla; la reversa de marcha es el bucket |
| Velocidad | `l_max_duty` | 0,95 | — | 0,95 | [VERIFICADO: mcconf_default.h MCCONF_L_MAX_DUTY 0,95; mantener] | — |
| Temperatura | `l_temp_fet_start / end` | 85 / 100 | °C | 85 / 100 | [VERIFICADO: mcconf_default.h; mantener] | — |
| Temperatura | `l_temp_motor_start / end` | 85 / 100 | °C | 85 / 100 | [CALCULADO: start = mín(85 default, t_winding_max_c 120 °C de inputs.yaml); end = start + 15 como el default] · default 85/100 [VERIFICADO: mcconf_default.h] | sizing toma t_winding_max_c como la temperatura donde el VESC EMPIEZA a limitar: no subir start sin rehacer el cálculo térmico. Requiere NTC 10 k en el bobinado (TEMP_SENSOR_NTC_10K_25C, R06 §1.2) |
| App | `app_to_use` | PPM | — | UART | [VERIFICADO: appconf_default.h APPCONF_APP_TO_USE = APP_UART → cambiar] | — |
| App PPM | `ctrl_type` | PPM_CTRL_TYPE_CURRENT | — | NONE | [VERIFICADO: https://raw.githubusercontent.com/vedderb/bldc/master/applications/app_ppm.c — reversa directa con signo] | Bucket, dwell y el único giro inverso (limpieza de rejilla) los gestiona el MCU (§5); alternativa DUTY si la bomba cavita (R06 §2.6) |
| App PPM | `pulse_start / center / end` | 1,0 / 1,5 / 2,0 | ms | 1,0 / 1,5 / 2,0 | [VERIFICADO: appconf_default.h] = salida del MCU (throttle_logic.c) | — |
| App PPM | `hyst (zona muerta VESC)` | 0,02 | — | 0,15 | [SUPUESTO: el MCU ya aplica la zona muerta; default 0,15 VERIFICADO se comería el 15 % inferior] | app_ppm.c aplica utils_deadband(servo, hyst) [VERIFICADO: app_ppm.c] |
| App PPM | `throttle_exp` | 0 | — | 0 | [VERIFICADO: default lineal; la expo la hace el MCU] | — |
| App PPM | `ramp_time_pos` | 1 | s | 0,4 | [SUPUESTO: redundante con la rampa del MCU (research/R06_electrica.md §2.6 ~1 s); default 0,4 s VERIFICADO] | — |
| App PPM | `ramp_time_neg` | 0,1 | s | 0,2 | [SUPUESTO: bajada rápida en el VESC; default 0,2 s VERIFICADO appconf_default.h] | — |
| App PPM | `safe_start` | true | — | true | [VERIFICADO: app_ppm.c MIN_PULSES_WITHOUT_POWER 50 → ≈ 1 s de neutro a 50 Hz [CALCULADO]] | — |
| General | `timeout_msec` | 250 | ms | 1000 | [SUPUESTO: 12 tramas PPM perdidas; default 1000 ms VERIFICADO appconf_default.h] | Sin PPM válido → corriente de freno de timeout [VERIFICADO: app_ppm.c] |
| General | `timeout_brake_current` | 0 | A | 0 | [VERIFICADO: appconf_default.h; 0 = rueda libre] | — |
| General | `kill_sw_mode` | KILL_SW_MODE_ADC2_HIGH | — | DISABLED | [VERIFICADO: https://raw.githubusercontent.com/vedderb/bldc/master/timeout.c — kill si V(ADC_EXT2) > 1,65 V, sondeo cada 10 ms] | Pull-up 10 kΩ a 3,3 V en ADC2; Q_EN + opto U3 lo llevan a GND solo con cordón+seta+MCU armado |
| General | `multi_esc` | false | — | true | [VERIFICADO: appconf_default.h APPCONF_PPM_MULTI_ESC true; un solo ESC] | — |
<!-- /ELEC:vesc -->

Notas: (1) `l_current_max` es el límite de corriente de FASE (par máximo, por debajo del corte del pasador) y en modo PPM *Current* se usa para acelerar **en ambos sentidos** [VERIFICADO: `app_ppm.c`, rama `PPM_CTRL_TYPE_CURRENT`]. El jet no usa el giro inverso para la marcha atrás: con el bucket abajo el MCU manda PPM en **avance** limitado a `reverse_limit` = 0,63 (PPM ≤ 1500 + 500 × 0,63 ≈ 1815 µs, P ≤ 50 %); el único PPM < 1500 µs es la limpieza de rejilla (≥ 1500 − 500 × `weed_cmd` = 1450 µs, ≤ 3 s), y su velocidad la topea `l_min_erpm`. `l_current_min` acota el **frenado**. Perfil COSTA/ABIERTO: `l_max_erpm` guardado = COSTA; ABIERTO lo pone `vesc_perfil.lisp` en RAM (§5.4). (2) `hyst` chico porque `app_ppm.c` aplica `utils_deadband(servo, hyst)` además de la zona muerta del MCU [VERIFICADO: app_ppm.c]. (3) `safe_start` del VESC exige 50 pulsos en neutro [VERIFICADO: `MIN_PULSES_WITHOUT_POWER 50`]: el MCU manda neutro desde el arranque y durante el segundo de armado, así que se cumplen solos. (4) `l_max_erpm` depende del número de polos: `si_motor_poles` = 10 sale de la ficha del MTI120116 (12N/10P); **contar los imanes** del motor real (o comparar rpm medidas con un tacómetro óptico contra ERPM/5 en VESC Tool) y, si difiere, corregir `pole_pairs` en `inputs.yaml` y regenerar (también reescribe `vesc_perfil.lisp`). (5) Detección de motor (FOC) con el acople motor–eje **desmontado** (motor solo). (6) Con FW ≥ 5.3 en un Flipsky 75100, `foc_phase_filter_enable = false` o se daña el ESC [VERIFICADO: R06 §2.1].

## 7. Cálculos del circuito

<!-- ELEC:calc -->
| Magnitud | Valor | Etiqueta / base |
|---|---|---|
| Pack | 2 × LiTime 36 V 60 Ah Golf Cart en paralelo (12S2P, BMS 2 × 120 A) → 12S LFP, 38,4 V nom., 43,8 V carga plena | [CALCULADO: inputs.yaml battery] · V/celda [ESTIMADO: research/R06_electrica.md §4.3, LFP 3,65 V/celda máx.] |
| R de precarga (en paralelo con K1) | 100 Ω, ≥ 30 W (carcasa de Al sobre la tapa-disipador) | [SUPUESTO: research/R06_electrica.md §3.4 (100 Ω → 5τ ≤ 1 s)]; potencia [CALCULADO: 1,5 × V²/R en corto del bus] |
| τ = R·C_bus / 5τ | 0,20 s / 1,00 s | [CALCULADO] con C_bus 2 mF [ESTIMADO: research/R06_electrica.md §3.4, C de bus del VESC 1–2 mF no publicado; se toma el mayor] |
| Pico de corriente / energía en R | 0,44 A / 1,92 J | [CALCULADO: V_máx/R; ½·C·V²] |
| Potencia máx. que pasa por R con K1 abierto | 4,8 W = 0,28 % del crucero (1709 W, sizing) | [CALCULADO: V²/4R] → sin empuje con K1 abierto |
| Espera con cordón AFUERA tras encender S1 | ≥ 2 s | [CALCULADO: ≥ 2 × 5τ, redondeado] |
| Bobina K1 | TE Connectivity KILOVAC EV200AAANA: bobina 9–36 V con economizador, alimentada a 12 V (11,8–12,2 V) desde B-12V → ✔ dentro de 9–36 V; cierre 3,8 A ≤ 130 ms, retención 0,13 A = 1,56 W | [VERIFICADO: hoja EV200 — bobina 'A' 9–36 V CC (opera), pickup máx. 9 V, dropout mín. 6 V] · [VERIFICADO: hoja EV200 — holding current 0,13 A @ 12 V (economizador incorporado, 1,7 W)] · [VERIFICADO: hoja EV200 — inrush máx. 3,8 A, inrush time máx. 130 ms] · [VERIFICADO: Mean Well RSD-60-SPEC (2026-07-09) — RSD-60L-12: 12 V, 5 A, entrada 18–72 V CC]; mando de K1 a 12 V (auditoría H3, R2-E1) · [VERIFICADO: Mean Well RSD-60-SPEC (2026-07-09) — tolerancia de salida ±2,0 %] |
| Apertura de K1 / fuerza contraelectromotriz | ≤ 12 ms; N1/N2 no bajan de 0 V al abrir (sin supresor externo) | [VERIFICADO: hoja EV200 — release (incluye arco) máx. 12 ms @ 2000 A; close típ. 15 ms] · [VERIFICADO: hoja EV200 — 'built-in coil economizer … limits back EMF to 0V'] |
| Consumo de bobina en la misión (0,75 h) | 1,17 Wh = 0,03 % de la energía usable (sizing) | [CALCULADO: P_retención × t]; con el bote amarrado y el clip PUESTO la bobina sigue tomando esa potencia (B-12V está aguas arriba de S1): sacar el clip al dejar el bote |
| Fusible de mando F2 (salida de B-12V, lento) | 5 A | [CALCULADO: primer valor normalizado ≥ 1,25 × I de cierre 3,8 A] · factor [SUPUESTO: fusible de mando (lento) ≥ 1,25 × corriente de cierre de la bobina] |
| Interruptor de cordón (Watski 12 V – 15 A) en el mando de 12 V | ✔ 12 V ≤ 12 V nominal; cierre 3,8 A ≤ 15 A; abre 0,13 A sin sobretensión inductiva (economizador). Alternativa Sea Dog 5 A: margen 1,3× sobre el cierre | [VERIFICADO: research/R08a §3 — Watski 'Dødmands kontakt universal' 12 V – 15 A] · [VERIFICADO: Sea Dog SD-420487-1, 5 A máx. (research/R06_electrica.md §3.2)] |
| R serie de U2+U3 (nodo bobina) | 1800 Ω, 5,2–5,5 mA, P 0,05 W → 0,25 W | [CALCULADO: E12 ≤ (12 V − 2·Vf)/I, mando de 12 V] [ESTIMADO: LED IR de optoacoplador típico 1,1–1,4 V] |
| R serie de U1 (nodo seta) | 1800 Ω, 5,9–6,1 mA, P 0,07 W → 0,25 W | [CALCULADO] |
| Tensión inversa en los LED de U1–U3 al abrir la bobina | N2 → -0 V (economizador de K1) vs V_R máx. 5 V → no hace falta diodo con el EV200; se deja el 1N4148 antiparalelo como protección si se reemplaza K1 por uno sin economizador | [VERIFICADO: hoja EV200 — 'built-in coil economizer … limits back EMF to 0V'] · [ESTIMADO: V_R máx. del LED de optoacopladores de fototransistor típicos 5–6 V; verificar en la hoja del elegido] |
| Precarga con el consumo en reposo del VESC | I_q ≤ 38,4 mA para llegar al 90 % con K1 abierto; al 80 % la energía del cierre de K1 es 59 mJ | [CALCULADO: 0,1·V_nom/R; ½·C·(0,2·V_nom)²] · [SUPUESTO: el consumo en reposo del VESC 75100 no está publicado; se mide en T0.3] |
| Corriente de colector mínima (CTR 50 %) vs pull-up | 2,60 mA ≫ 0,50 mA (5 V) / 0,33 mA (3,3 V) | [CALCULADO] [SUPUESTO: especificación mínima de compra CTR ≥ 50 %] |
| Retención de la bobina (hueco del riel de 12 V al arrancar el achique) | P del nodo 1,78 W (bobina + 3 LED), de 11,26 V a 9,0 V en 0,25 s → C ≥ 19,4 mF → **22 mF** (cubre 0,28 s); bomba 2–8 A vs DC-DC 5 A con límite de corriente | [CALCULADO: C = 2·P·t / (V0² − V²)] · [VERIFICADO: hoja EV200 — Hold Voltage (Min.) 7,5 V CC (bobina 'A')] · [SUPUESTO: no bajar de 9 V (pickup máx. de la hoja EV200) durante el hueco: margen de 1,5 V sobre la retención mínima] · [SUPUESTO: hueco del riel de 12 V al arrancar la bomba de achique contra el límite de corriente del DC-DC (arranque < 0,1 s × 2,5); lo valida T0.4] · [ESTIMADO: Schottky 3 A (1N5822) a 0,2 A] · [ESTIMADO: Attwood Sahara S500 ≈ 2 A en marcha y ~4× en el arranque (motor CC); la ficha no se abrió] · [VERIFICADO: Mean Well RSD-60-SPEC (2026-07-09) — RSD-60L-12 5 A; sobrecarga 105–135 % con limitación de corriente constante] |
| Consumo en reposo (bote amarrado, S1 abierto) | DC-DC 0,5–1,5 W → la energía usable dura 115–346 días; con el clip PUESTO (+1,56 W de bobina) 56–84 días. Invierno: sacar F5 (y los F_BR) y guardar la batería a carga de almacenamiento | [CALCULADO: E usable de sizing / P] · [ESTIMADO: consumo en vacío de un DC-DC aislado de 60 W; la ficha no lo publica — medir en T0.4] |
| Cortocircuito presunto (bornes de batería, sin cable) | una batería 0,9–4,4 kA; las 2 en paralelo 1,8–8,8 kA vs MRBF 2 kA a 58 V (✘ NO alcanza) y Class T 20 kA (✔) → F1 y F_BR Class T | [CALCULADO: V_máx / R_int] · [ESTIMADO: LiTime no publica la R interna (página 2026-10-02); 0,050 Ω = Power Queen 24 V 50 Ah 'R int. ≤ 40 mΩ' (R08a, VERIFICADO) escalada a 12S 60 Ah; 0,010 Ω = 12 celdas prismáticas de 60 Ah de ≈ 0,5 mΩ + BMS y bornes] · [VERIFICADO: research/R06_electrica.md §5.4 — MRBF 10 kA @ 14 V / 5 kA @ 32 V / 2 kA @ 58 V] · [VERIFICADO: Blue Sea 5113 Class T — '20,000 Ampere Interrupt Capacity (AIC)', 160 V CC máx. (fisheriessupply.com, 2026-10-02)] |
| Fusibles F1 (barra +) / F_BR por rama / cable DC | 250 A (mín. 218,9) / 2 × 150 A / 70 mm² | [CALCULADO: resultados/sizing.json fuse_a, fuse_branch_a (rama = reparto 60/40 × I pico), cable_dc] |
| Fases ESC → motor | cables propios: motor 6 AWG × 300 mm a ESC 8 AWG, unión con conectores bala 8 mm (sin el tramo de 95 mm² de sizing); caída ≈ 1,48 % a 292 A | [CALCULADO: ρ·L/A con 6 AWG 13,3 mm² × 0,30 m + 8 AWG 8,37 mm² × 0,20 m [ESTIMADO: largo del cable del ESC no publicado]] · calibres [inputs.yaml motor/esc leads, allí VERIFICADO] · sección del tramo: §4 Cables |
<!-- /ELEC:calc -->

Procedimiento de encendido que se deriva: **S1 ON con el cordón AFUERA** → esperar el tiempo de la tabla (la R_pre carga el bus) → colocar el cordón (K1 cierra sobre un bus ya cargado) → soltar el acelerador 1 s → armado. Si se enciende con el cordón puesto, K1 cierra sobre el bus descargado: el pico lo limita solo la ESR [VERIFICADO: R06 §3.4, "thousands of Amps… weld contacts"]; el antichispa opcional aguas abajo evita ese caso.

## 8. Modos de falla del propio circuito

| Falla | Efecto | Detección | Resultado / mitigación | ¿Seguro? |
|---|---|---|---|---|
| **K1 soldado** | El cordón ya no corta la potencia | Sin "clic" al poner/sacar el cordón; con cordón afuera y S1 ON, tensión sobre los bornes de K1 ≈ 0 V en vez de la caída del VESC por R_pre [ESTIMADO: > 1 V con el VESC encendido] | Quedan U3→ADC2, MCU neutro y Q_EN (§3). T0.15 prueba esa situación. Probar el clic **antes de cada salida** | Sí (2 barreras) |
| K1 con bobina abierta / no cierra | Sin propulsión | No arranca | Remos; revisar bobina/F2 | Sí |
| B-12V sin salida (F5 o F2 fundido, DC-DC dañado) | Bobina sin corriente → K1 abre; también se pierden el achique y la alarma | LED destello 2 s (U2/U3 apagados); achique sin luz | Fail-safe para la propulsión; remos; revisar F5/F2 antes de salir (prueba previa) | Sí (sin propulsión ni achique) |
| Bobina de K1 con tensión fuera de rango | El EV200 opera con 9–36 V [VERIFICADO: hoja EV200]; B-12V da 12 V ± 2 % [VERIFICADO: RSD-60-SPEC] | T0.4 (V de bobina) | Si B-12V se reemplaza, mantener 9–36 V | Sí |
| **Hueco del riel de 12 V al arrancar la bomba de achique** (mismo DC-DC de 5 A con límite de corriente) | Sin retención, la bobina podría bajar de la retención mínima (7,5 V) y K1 abriría en marcha (pérdida de propulsión espuria) | T0.4 b (osciloscopio en la bobina con el flotador levantado) | Schottky + 22 mF (B-HOLD) aguas arriba de seta/cordón: cubre ≈ 0,28 s sobre 9 V (§7) sin demorar el corte por cordón/seta | Sí si pasa T0.4 b |
| LED de U1–U3 en inversa al abrir la bobina | Con el EV200 (economizador) N1/N2 no bajan de 0 V (§7); con un contactor de reemplazo SIN economizador irían a −(Vd + I·R_supresor) | T0.4 (V(N2)) | 1N4148 antiparalelo en cada LED se deja igual (§4) | Sí |
| **Fusible de rama F_BR fundido** (o borne/cable de rama suelto) | La otra batería sola lleva toda la corriente: a fondo 192 A > 120 A de su BMS → el BMS corta (pérdida de propulsión) o la batería trabaja sobrecargada | **No se ve por tensión** (la barra alimenta el cable de rama desde el otro lado): pinza amperimétrica CC en cada cable de rama con el bote amarrado y el motor al 30 % (ambas ramas con corriente y reparto ≤ 60/40), o caída en mV sobre cada F_BR (≈ 0 mV = abierto) | Prueba previa (§10, checklist §3): si una rama no lleva corriente, no salir | Sí (pérdida de propulsión) |
| **Hall de la palanca trabado DENTRO de la banda válida** (imán corrido, sensor despegado pero con salida intermedia) | El MCU no lo distingue de una palanca quieta: mantiene el último comando válido o queda en neutro | Sin detección automática (solo `SENS_LOW/HIGH` fuera de banda y `SENS_JUMP`) | **Riesgo residual**: el cordón y la seta cortan por hardware; prueba previa de recorrido completo (0 → 100 % → 0 en la telemetría); P2: segundo hall redundante y comparación | Parcial (lo cubren cordón/seta) |
| **Bucket a medio camino / trabado** | Solo hay fin de carrera de bucket ARRIBA (D5 NC): "abierto" = abajo, a medio camino o cable cortado, y el MCU limita a `reverse_limit` en avance; no hay fin de carrera de bucket ABAJO, así que un bucket trabado a mitad de carrera no se distingue de "abajo" | `BKT_DOWN` en la telemetría con la palanca del bucket arriba | **Riesgo residual**: empuje a `reverse_limit` con dirección incierta (parte del chorro desviado); mitigación: inspección visual del bucket en la prueba previa; P2: segundo fin de carrera (bucket ABAJO) y estado "ni arriba ni abajo" → salida 0 | Parcial |
| **MOSFET del antichispa en corto** | Se pierde el arranque suave | Bus cargado sin presionar el botón | K1 sigue aguas arriba [VERIFICADO: R06 §3.1, falla en corto] | Sí |
| R_pre en corto o puenteada | Equivale a K1 soldado | Mismo método que K1 soldado | ídem | Sí (2 barreras) |
| R_pre abierta | Sin precarga → K1 cierra sobre bus descargado → desgaste/soldadura de K1 | T0.3: el bus no sube con el cordón afuera | Reemplazar; inspeccionar K1 | Sí (pierde vida K1) |
| **Cable del cordón cortado / J2 suelto / F2 fundido** | Bobina sin corriente → K1 abre; U2/U3 apagan | LED destello 2 s | Fail-safe por diseño (NC-con-clip en serie) | Sí |
| **Corto entre los dos conductores del cordón** (cable aplastado en la caña, agua salada en J2) | Puentea el cordón para K1 **y** U2/U3: **tirar del cordón no corta** | Solo con la prueba de cordón **antes de cada salida** (latente) | Seta sigue funcionando; cable redondo protegido dentro del tubo de la caña con alivio de tensión; grasa dieléctrica en J2; en P2 evaluar interruptor de 2 contactos (2 canales) | **No** (falla latente: única combinación peligrosa) |
| Cable de la seta cortado | K1 abre | LED destello | Fail-safe | Sí |
| U2 en corto (C–E) | El MCU no ve el cordón | Con el cordón afuera el LED NO destella | K1 y U3 cortan igual; T0.12 detecta | Sí (2 barreras) |
| U3 en corto | Se pierde el kill por hardware del VESC | T0.14 b: con Q_EN puenteado y el cordón afuera, V(ADC2) queda baja | K1, Q_EN y PPM neutro siguen | Sí |
| Q_EN en corto | El MCU no puede poner al VESC en kill | T0.14 c: cordón puesto y MCU desarmado, V(ADC2) queda baja | U3 y K1 siguen; PPM neutro | Sí |
| Pull-up de ADC2 suelto | ADC2 flotante: kill por software indeterminado | T0.14 b/c: V(ADC2) no llega a 3,3 V | K1 + PPM | Sí |
| **MCU colgado** | — | WDT de hardware 120 ms → reset → pines en alta impedancia | Q_EN abre (kill del VESC) y no hay PPM (pull-down → timeout); arranca `DISARMED`; T0.18 | Sí |
| MCU sin alimentación (DC-DC o F3) | Sin PPM, Q_EN abierto | LED apagado | Kill del VESC + timeout | Sí |
| MCU en bucle de reset (bootloader viejo + WDT) | Sin propulsión | LED/serie | Regrabar bootloader (Optiboot) | Sí |
| **Pérdida de señal PPM** (cable cortado/suelto, en corto a 5 V o GND) | Sin flancos válidos | VESC Tool: timeout | Timeout del VESC → freno 0 A (rueda libre) + safe start [VERIFICADO: `app_ppm.c`] en ≤ `timeout_msec` (§6) | Sí |
| **Fin de carrera del bucket**: cable cortado / contacto abierto | El MCU ve "bucket ABAJO" | `BKT_DOWN` (+ `BKT_MISM` con la palanca en avance) en la telemetría | Avance limitado a `reverse_limit` (fail-safe: se vuelve con potencia reducida); si ocurre acelerando: salida 0 hasta soltar (`BKT_HOLD`) | Sí |
| Fin de carrera pegado cerrado (o en corto) con el bucket abajo | El MCU ve "ARRIBA" con la palanca del lado de reversa | `BKT_MISM`; T0.5/T0.10 | Palanca de reversa → salida 0: se pierde la marcha atrás, nunca hay avance inesperado | Sí (pierde la reversa) |
| Enclavamiento mecánico roto (acelerador fuera de cero al mover el bucket) | Cambio de bucket con empuje | `BKT_HOLD` | Salida 0 en el mismo tick hasta volver el acelerador a cero; reversa ≤ 0,63 siempre | Sí |
| Selector de perfil: cable cortado | Lee COSTA | Telemetría `COSTA` | 5 kn | Sí |
| Pulsador de rejilla en corto o trabado | Pulsador "apretado" permanente | `WEED_WAIT` / LED | Exige soltarlo entre usos: un corto nunca inicia el giro inverso; si se traba durante una limpieza, corta a los 3 s | Sí |
| Línea D12 → ADC1 cortada, script LispBM no cargado o VESC reiniciado | El VESC queda en el `l_max_erpm` guardado | T0.20 | Perfil COSTA (5 kn) aunque el selector diga ABIERTO | Sí (pierde velocidad) |
| Hall: señal o 5 V cortados | ADC ≈ 0 V (pull-down 100 kΩ) | `SENS_LOW`, LED 10 Hz | Neutro + `FAULT` en el mismo tick | Sí |
| Hall: GND cortado | Salida hacia 5 V o valor intermedio [ESTIMADO: no documentado para el A1324] | `SENS_HIGH` o `SENS_JUMP` | T0.16 prueba los 3 hilos por separado; si GND abierto da un valor "válido", bajar el pull-down a 10 kΩ | A verificar en T0.16 |
| Imán despegado / sensor saturado | Lectura fija ≈ centro o en un extremo | No acelera / no arma | Neutro (centro) o `NOT_ZERO`/`FAULT` (extremo) | Sí |
| Ruido del motor en A0 | Falso `SENS_JUMP` | `FAULT` espurio | Promedio de 4 muestras + RC + cable apantallado (J1 con malla) | Sí (disponibilidad) |
| Configuración del VESC por defecto (kill deshabilitado, `hyst` 0,15, `battery_cut` 10/8 V, timeout 1 s) | Barreras 2 y 4 degradadas | T0.6: leer y comparar | Tabla §6 | Sí con T0.6 |
| BMS abre bajo carga | Pérdida de propulsión; pico de tensión al regenerar | — | `l_max_vin` < entrada máx. del DC-DC (§6); `l_in_current_min` limita la regeneración | Sí (remos) |
| BAT− a casco (aislación perdida) | Corrientes parásitas/galvánicas | T0.1 (> 1 MΩ) antes de cada temporada | Buscar el contacto | Sí (no inmediato) |
| Agua dentro de la caja ESC | Puentes en ADC2/optos; VESC en falla | T1, papel tisú | IP68 + O-ring + respiradero (§9); K1 aguas arriba sigue | Sí (pérdida de propulsión) |

## 9. Estanqueidad: conectores, prensaestopas, recubrimientos

- **Caja ESC (P1-ELE-01):** sello axial con O-ring de NBR 70 y grasa de **silicona** (compatible con NBR/EPDM/FKM; nunca grasa mineral con EPDM ni grasa de silicona con O-rings de silicona) [VERIFICADO: R05 §B, tabla de compatibilidad S24]; cara de apoyo refrentada o con epoxi + lijado [ESTIMADO: R05 §B4]. Limpiar el PETG con IPA:agua 50:50; **nunca MEK** (disuelve el PETG) [VERIFICADO: R05 S34]; evitar también la acetona por precaución [ESTIMADO: R05 aclara que S34 no la menciona y que su efecto sobre el PETG no está verificado].
- **Prensaestopas:** **un cable redondo por prensaestopas** (dos cables o un cable plano no sellan) [ESTIMADO: R05 §B8]; rosca en PETG **pasante con contratuerca** y junta sobre cara plana [R05 §B8]; caja de batería: **M32** (13–21 mm) para cada cable de 70 mm² (B-GLAND32; Ø ext. ≈ 17 mm [ESTIMADO: medir]); el ESC (IP65) no lleva prensaestopas de potencia: sus cables propios de 8 AWG salen por la ranura de la capota P1-ELE-02 y se unen a los terminales de 70 mm² (B-LUG10) y a los del motor (balas de 8 mm, B-PHCON); M16 4–8 mm para el cable del hall y el del cordón (**dos** cables de señal → dos prensaestopas) [VERIFICADO: R08a §8 / BOM B-GLAND16]. Referencia de calidad: LAPP SKINTOP ST-M M20, IP68 5 bar/30 min, junta CR anti-UV, cable 6–13 mm [VERIFICADO: R05 S40]. Verificar el diámetro exterior real de cada cable contra el rango del prensaestopas antes de perforar [SUPUESTO: el OD del 70 mm² estañado no está medido].
- **Extremos de cable:** termocontraíble **con adhesivo** en cada punta y terminal: el agua viaja por dentro de un cable multifilar mojado [ESTIMADO: R05 §B8]. Lazo de goteo antes de cada prensaestopas; prensaestopas en caras laterales o inferiores, nunca arriba [SUPUESTO].
- **Conectores de la caña:** J1 Lumberg 0332-04/0322-04 (4 polos apantallado) y J2 Cliffcon 68 (2 polos), ambos IP68 [VERIFICADO: R08a §8]. Alternativa de mayor robustez: Bulgin 900 Buccaneer, IP68 10 m/2 semanas, niebla salina EN 60068-2-52 [VERIFICADO: R05 S41]. **Grasa dieléctrica de silicona** en juntas y contactos al armar; tapas puestas cuando están desconectados; enjuagar con agua dulce después de cada salida [ESTIMADO: práctica habitual].
- **PCB (Nano, placa de optos/Q_EN, DC-DC):** barniz conformal (acrílico o silicona) en las dos caras, **enmascarando** conectores, USB y bornes [ESTIMADO: práctica habitual]; aplicarlo y curarlo **antes** de montar en la caja de PETG (sus solventes pueden atacar el PETG [ESTIMADO: R05 S34, solventes]).
- **Respiradero de membrana ePTFE M12** en una cara lateral baja de la caja: iguala presión y evita que la caja "aspire" agua por los sellos al enfriarse (bombeo térmico) [ESTIMADO; necesidad: R03/R05, BOM B-VENT].
- **Sensor hall:** encapsulado en epoxi dentro de P1-ELE-04 (la West 105/205 tiene HDT 48 °C [VERIFICADO: R05 S21]: suficiente en la caña, lejos del motor); salida por prensaestopas M12 con cable redondo.
- **Motor y fases:** el motor es SECO y está fuera del agua: conectores bala dentro del capó con drenaje, sin conector IP68 [VERIFICADO: R05 §B8, "Un conector IP68 solo hace falta si se pasa a un pod"].
- **Batería:** caja estanca sobre el nivel de sentina [VERIFICADO: R06 §5.1, ISO 13297 8.1]; cubrebornes; batería que estuvo sumergida en agua salada = no cargar, aislar al aire libre y descartar [VERIFICADO: R06 §4.2].
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

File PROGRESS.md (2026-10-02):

# PROGRESS — P1-J waterjet eléctrico para el jet boat de Jorge

Leyenda: [x] hecho · [~] en curso · [ ] pendiente

> **Cambio de alcance (2026-10-01, pedido del usuario):** el proyecto pasó de una cola larga eléctrica
> para un jon boat a un **waterjet eléctrico inboard** para el jet boat de 2,30 m de Jorge (D-01).
> Las tres pasadas se rehicieron para el waterjet; la versión anterior queda en git (`5dfada0`).

## Pasada 1 — Funcional de punta a punta (waterjet) ✅
- [x] Investigación nueva: R10b (plano de Jorge auditado), R11 (componentes y precios del jet), R12 (métodos de bomba, toma y planeo), R13 (normativa DK del jet)
- [x] inputs.yaml reescrito (casco, masas, waterjet, motor/ESC/batería, comparación, BOM)
- [x] sizing.py + p1calc/{hull, planing, waterjet}: hidrostática, Savitsky + joroba, momento del chorro, curva de bomba, cavitación, energía, térmico, eje, pasador; optimizador paralelo
- [x] CAD de 65 piezas (toma, bomba, tren, motor, dirección, reversa, mandos, electrónica, batería, casco de referencia) con marcos BOTE/JET
- [x] verify_parts.py (boquilla ±25° × bucket) y structural.py — OK
- [x] BOM, arquitectura (matriz A–F), comprar vs construir (JT132)
- [x] run_all.py exit 0

## Pasada 2 — Profundidad ✅
- [x] Planos acotados de piezas mecanizadas/soldadas (`04_diseno/planos/`)
- [x] Electrónica: cables, fusibles, diagrama; firmware v2.0 (bucket, perfiles costa/abierto, limpieza de rejilla, kill) + 69 tests
- [x] Visor 3D web para Jorge (ensamblado, explosión, dirección, bucket, chorro, demo, corte lateral)
- [x] FEA de piezas críticas del jet (`04_diseno/fea`: DRV-03, REV-01, STE-01, INT-02, CTL-02)
- [x] 05_fabricacion.md + probetas + PrusaSlicer
- [x] 06_ensamblaje_y_pruebas.md + FMEA + checklist_salida.md + PENDIENTES_GASPAR.md
- [x] 01, 02, 03, 07, decisiones.md, README reescritos

## Pasada 3 — Auditoría adversarial
- [x] Ronda 1 (44 hallazgos, corregidos)
- [x] Ronda 2 (27 hallazgos, corregidos)
- [x] Ronda 3 (FEA de piezas críticas; superada por la ronda 4: auditoria.md)
- [x] Ronda 4 (rediseño de la traba del bucket, del pivote y del desbloqueo; FEA de REV-01/STE-01 rehecho; corrida fina en `c25d433`): superada por la re-auditoría de la ronda 5
- [x] Ronda 5 (re-auditoría adversarial del rediseño de la ronda 4: MEC-01…09, DES-01…08, FEA-R5-01…04; cerrada en software con la corrida completa final): correcciones en el repositorio; R5-N1 y R5-N5 resueltos en el diseño con el cuerpo del émbolo ajustado (Ø24 H7/h6 con Loctite 641, sin rosca ni precarga), el piloto Ø24 y los lóbulos engrosados de las orejas, y R5-N2…R5-N4 corregidos; re-auditoría del cierre (MECH-1…10, CALC-1…4, FEA-1…5, TEST-1, DOC-1) corregida o documentada, con el pivote en dos piezas (MECH-1); **cerrada en software**: corrida completa final con exit 0 (FEA de la oreja: FS <!--V:fea.piezas.P1-STE-01.FS_min:.2f-->2.52<!--/V-->, objetivo 2); abiertos declarados: R5-N6 (medición física) y FEA-5 (limitación del método)
- [x] Prueba de regeneración desde inputs.yaml (`tests/test_regeneration*.py`, auditoria.md §Regeneración)

## Definición de terminado (sección 9)
- [x] `pip install -r requirements.txt && python run_all.py` exit 0 (corrido completo, no `--fast`, con el FEA; 2026-10-02)
- [x] `pytest` pasa (incluida la regeneración completa `tests/test_regeneration_full.py`)
- [x] Toda pieza impresa: STEP + STL, manifold, ≤ 210×210×260, sin interferencias en todos los estados
- [x] Cambio en inputs.yaml regenera todo (probado y documentado)
- [x] FS por caso de carga ≥ 3 PETG / ≥ 2 metal (los que no llegaban se rediseñaron: auditoria.md); FEA fino de las 5 piezas críticas sobre el objetivo
- [x] Números etiquetados; links abiertos en esta sesión (research/R10b–R13)
- [x] Coherencia .md ↔ código (`tools_check_md.py` con 0 problemas)
- [x] auditoria.md sin críticos abiertos *de la propulsión* (la estabilidad del casco queda como bloqueante físico declarado; R5-N6 y FEA-5 abiertos y declarados)
- [x] README completo
- [x] Todo commiteado y pusheado; rama integrada en `main` y sitio publicado en GitHub Pages
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

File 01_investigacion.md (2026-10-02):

# 01 — Investigación: waterjet eléctrico inboard para el jet boat de Jorge

Resumen de lo que se aprendió, con la fuente de cada dato. El detalle y los links están en `research/`:
[R10a](research/R10a_toma_waterjet.md) (toma), [R10b](research/R10b_auditoria_plano_jorge.md) (auditoría del
plano), [R11](research/R11_componentes_jet.md) (componentes y precios), [R12](research/R12_metodos_waterjet.md)
(métodos de bomba, planeo y cargas), [R13](research/R13_legal_jet.md) (normativa), y de la etapa anterior
[R03](research/R03_proyectos_jet_ducted_efoil.md) (jets impresos), [R05](research/R05_materiales_sellado.md)
(PETG y sellado), [R06](research/R06_electrica.md) (eléctrica y seguridad) y [R07](research/R07_dinamarca.md)
(Dinamarca, agua y viento).

Etiquetas: [VERIFICADO: fuente] · [CALCULADO] · [ESTIMADO: base] · [SUPUESTO]. Los números que salen del
código de este proyecto van entre marcadores `<!--V:…-->` y los actualiza `docgen.py`; los de la
investigación se citan con su informe.

## 0. Resumen ejecutivo

1. **El plano de Jorge es un croquis conceptual, no un plano fabricable.** Las vistas no comparten escala
   (dispersión del 26 %), la toma está detrás del impulsor, el corte no tiene conducto de admisión, falta el
   sello y la boquilla queda dentro de la carcasa [CALCULADO: R10b §2, §4.1]. Se rehízo el diseño entero; del
   plano quedan los requisitos (1 piloto, ≥ 30 km/h, motor directo, toma enrasada, boquilla y reversa).
2. **Jorge tenía razón con la rejilla.** El agua tiene que entrar a proa del impulsor y subir por una rampa
   hasta su cara. En el plano la rejilla estaba 22–25 cm a popa de la cara del impulsor, del lado de descarga,
   y el eje quedaba sobre la flotación: la bomba no cebaba [CALCULADO: R10a §1–§3].
3. **La estabilidad del casco es el riesgo n.º 1.** Con 0,80 m de manga y el piloto sentado alto, el GM sale
   entre −113 y +90 mm según la posición del piloto [CALCULADO: R10b H1]; con el modelo de este proyecto,
   GM = <!--V:sizing.hydrostatics.GM_m:.3f-->0.010<!--/V--> m. La propulsión no lo resuelve (D-04).
4. **La masa realista es 165–242 kg, no 150** [ESTIMADO: R10b §4.2]. Con más de ~200 kg, 5 kW continuos no alcanzan para 30 km/h
   sostenidos [CALCULADO: R10b H13–H14]. Este diseño llega a <!--V:sizing.performance.vmax_cont_kmh:.1f-->24.0<!--/V--> km/h
   sostenidos y <!--V:sizing.performance.vmax_peak_kmh:.1f-->28.1<!--/V--> km/h por ratos (02 §5).
5. **Motor y tensión.** El HPM5000 de catálogo gira muy lento para un impulsor chico (≈ 91 rpm/V a 48 V); el
   Maytech MTI120116 150 KV refrigerado por agua sí sirve en ≤ 50 V [VERIFICADO: R11 §0, §1]. No hay packs
   LFP 13S comerciales en la UE: la opción ≤ 50 V es 12S (2 × LiTime 36 V 60 Ah) [VERIFICADO: R11 §3].
6. **Comprar la bomba es una opción seria.** La AWT JT132 (Ø130, 12 kg, dirección y reversa incluidas) cuesta
   ≈ 1000–1100 USD FOB [ESTIMADO: buscador, R11 §4] y resuelve las piezas más difíciles de fabricar.
7. **Legal.** Probablemente no es "vandscooter" si el piloto va sentado *dentro* del casco; no es speedbåd
   por debajo de 19 kW; los 30 km/h solo son legales a más de 300 m de la costa, en el centro de Als Fjord, y
   nunca en Als Sund (4 kn) [VERIFICADO: R13 §0]. Confirmar por escrito (R13 §8).
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

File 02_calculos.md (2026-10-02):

# 02 — Memoria de cálculo del waterjet (sizing.py)

Todo sale de [`sizing.py`](sizing.py) y de los modelos de [`p1calc/`](p1calc/) (`hull`, `planing`,
`waterjet`, `motor`, `power`), leyendo [`inputs.yaml`](inputs.yaml). Los casos estructurales están en
`04_diseno/structural_*.py`. Ningún número calculado está escrito a mano: las tablas entre marcadores
`AUTO` y los valores entre marcadores `<!--V:…-->` los rellena `python docgen.py` desde `resultados/*.json`.
Las entradas de `inputs.yaml` se citan con su etiqueta.

Etiquetas: [VERIFICADO: fuente] · [CALCULADO] · [ESTIMADO: base] · [SUPUESTO].
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

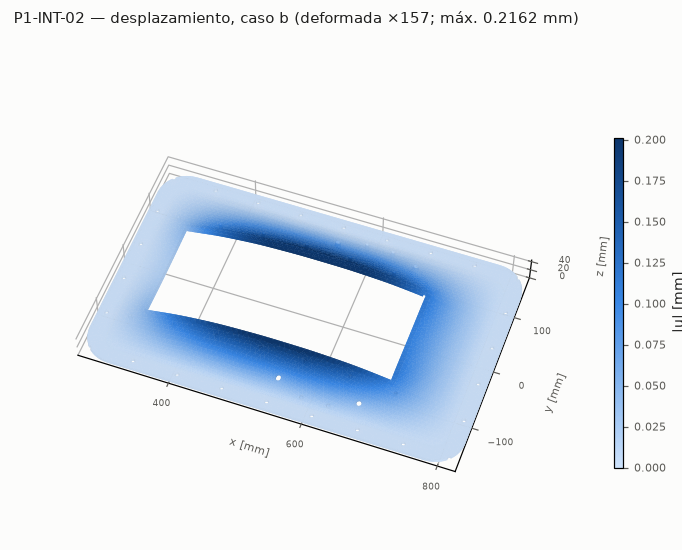
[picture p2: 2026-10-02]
04_diseno/fea/img/P1-INT-02_deformada.png

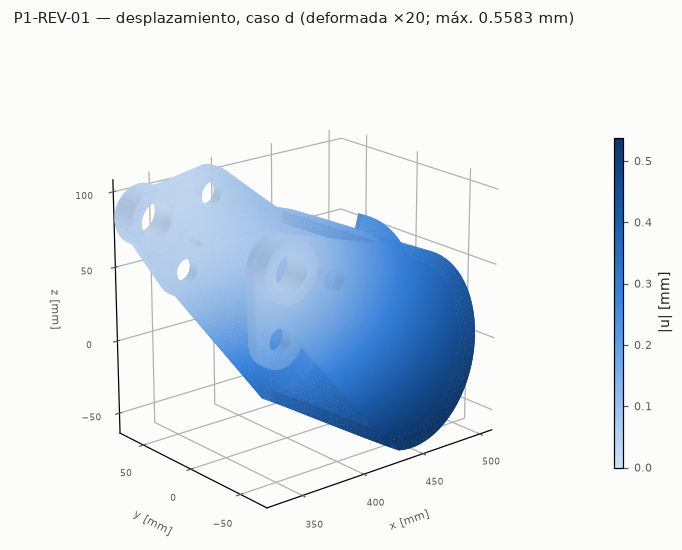
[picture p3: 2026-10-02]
04_diseno/fea/img/P1-REV-01_deformada.png

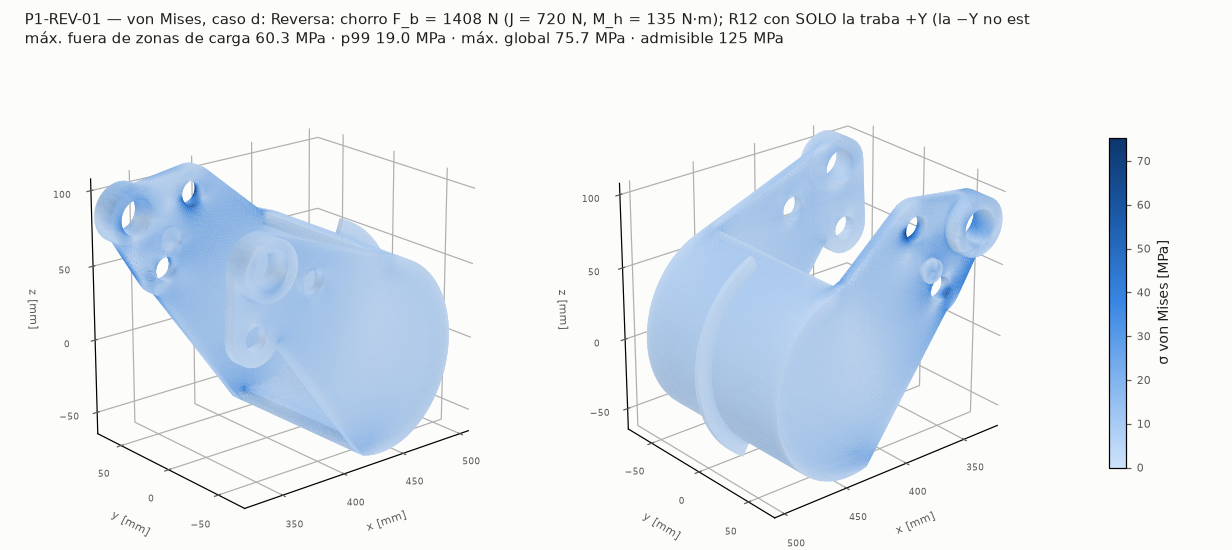
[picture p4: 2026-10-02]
04_diseno/fea/img/P1-REV-01_vm.png

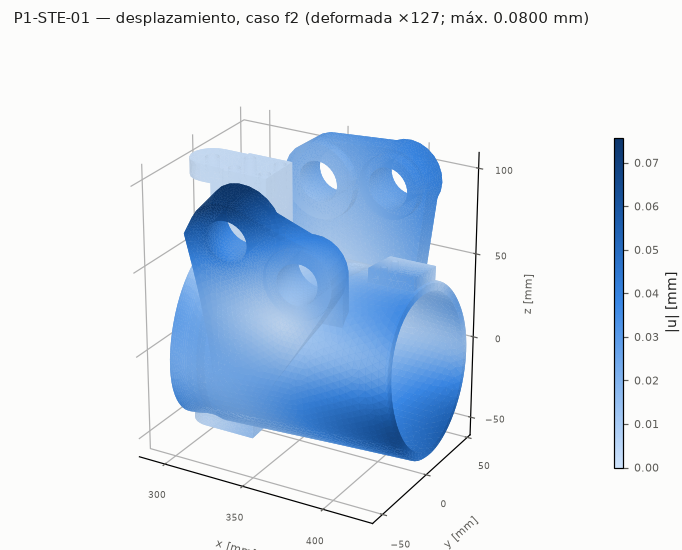
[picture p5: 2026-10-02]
04_diseno/fea/img/P1-STE-01_deformada.png

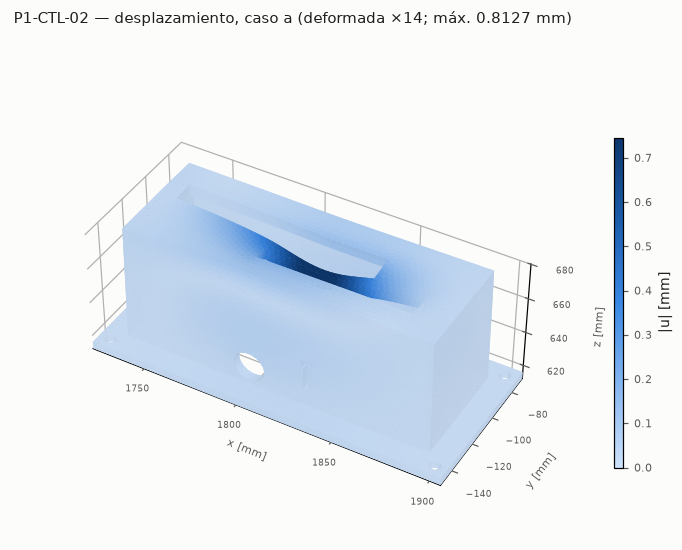
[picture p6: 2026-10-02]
04_diseno/fea/img/P1-CTL-02_deformada.png

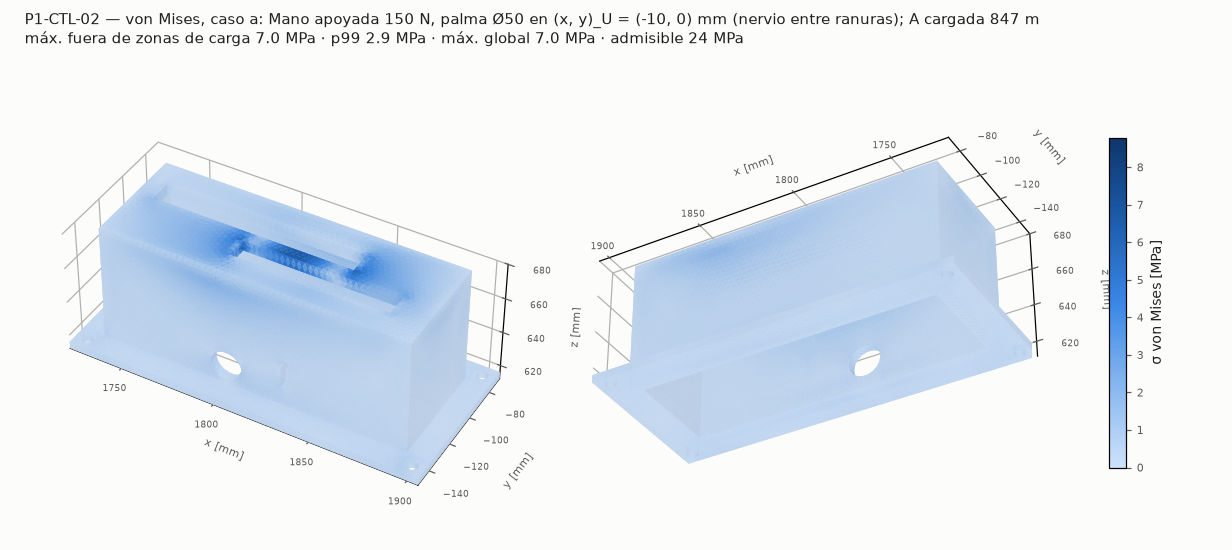
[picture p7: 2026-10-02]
04_diseno/fea/img/P1-CTL-02_vm.png

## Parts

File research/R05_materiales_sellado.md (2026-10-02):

# R05: materiales FDM en agua salobre y sellado

Consulta: 2026-10-01. Autor: subagente de investigación P1.

**Alcance.**
- **Parte A (materiales):** PETG, ASA, PC y PC-blend, PA-CF y PETG-CF, y recubrimiento epoxi, impresos en una Ender-3 S1 (≤260 °C, sin cerramiento) para servicio en agua salobre (Als Fjord). Factores de reducción de diseño, insertos roscados y compatibilidad química.
- **Parte B (sellado):** O-rings según Parker ORD 5700, ISO 3601-2 y Trelleborg; rugosidad FDM; sellos de eje; motor inundado, sellado o seco; prensaestopas y conectores IP68.

Complementa a R01 (videos), R02 (fueraborda y long-tail) y R03 (jet, rim y eFoil). Donde esos archivos ya verificaron algo, remito a ellos.

---

## 0. Método, etiquetas y fuentes

**Etiquetas.**
- `[VERIFICADO: Sx]`: el dato está en la fuente Sx de la tabla de abajo. La abrí en esta sesión (PDF bajado con `curl` y leído con `pdftotext`, o página leída con WebFetch).
- `[CALCULADO: …]`: cuenta mía con datos verificados o de `inputs.yaml` y `resultados/sizing_tablas.md`.
- `[ESTIMADO: base]` y `[SUPUESTO]`: lo que dicen. `[ESTIMADO: memoria técnica, no verificado]` = lo recuerdo, pero no lo encontré en una fuente abierta.

**Límites de lo leído.**
- ScienceDirect, MDPI (sitio), Springer y BSSA respondieron 403 o un desafío anti-bot.
- De tres papers leí **solo el resumen**: S12 (vía OUCI), S13 y S14 (vía la API de DOAJ).
- Los TDS de fabricantes son valores "típicos", medidos sobre probetas chicas con 100 % de relleno y casi siempre **ventilador apagado**. No son valores de diseño; lo dicen los propios TDS [VERIFICADO: S2, S5].
- **No vi ningún video.** El ensayo de adhesivos de Cosel y el de Half-Baked-Research los cito solo por el resumen de Hackaday (S23, S35).

| Id | Fuente (abierta en esta sesión) | URL |
|---|---|---|
| S1 | Prusament PETG, TDS v1.1 (2022) | https://www.prusa3d.com/file/2765253/prusament-petg-technical-data-sheet.pdf |
| S2 | Polymaker PolyLite PETG, TDS V6.0 (2026) | https://polymaker.com/wp-content/uploads/TDS_Polymaker_PolyLite-PETG_V6.0_2026-06-09_EN.pdf |
| S3 | Bambu Lab PETG Basic, TDS V3.0 | https://store.bblcdn.com/s1/default/cb94589bf7994fdcbfa833badefae9cd/Bambu_PETG_Basic_Technical_Data_Sheet.pdf |
| S4 | Polymaker Fiberon PETG-rCF08, TDS V1.0 | https://fiberon.polymaker.com/wp-content/uploads/TDS_FIBERON-PETG-rCF08_V1.0_EN.pdf |
| S5 | Polymaker ASA, TDS (wiki) | https://wiki.polymaker.com/polymaker-products/more-about-our-products/documents/technical-data-sheets/abs-asa/polymaker-tm-asa.md |
| S6 | Polymaker PolyLite PC, TDS (wiki) | https://wiki.polymaker.com/polymaker-products/more-about-our-products/documents/technical-data-sheets/polycarbonate/polylite-tm-pc.md |
| S7 | Polymaker PC-PBT, TDS (wiki) | https://wiki.polymaker.com/polymaker-products/more-about-our-products/documents/technical-data-sheets/polycarbonate/polymaker-pc-pbt.md |
| S8 | Polymaker Fiberon PA6-CF20, TDS V1.1 | https://cdn.shopify.com/s/files/1/0548/7299/7945/files/TDS_FIBERON_PA6-CF20_V1.1_EN.pdf?v=1733846088 |
| S9 | Polymaker Fiberon PA12-CF10, TDS V1.1 | https://cdn.shopify.com/s/files/1/0548/7299/7945/files/TDS_FIBERON_PA12-CF10_V1.1_EN.pdf?v=1740427088 |
| S10 | Polymaker wiki, PA6-CF20 (requisitos de impresión) | https://wiki.polymaker.com/polymaker-products/polymaker-filaments/fiberon-tm/fiberon-tm-pa6-cf20.md |
| S11 | Moreno Nieto et al., *Polymers* 2021, PLA/PETG en agua dulce, salada y azucarada | https://pmc.ncbi.nlm.nih.gov/articles/PMC8036839/ |
| S12 | Gama et al., *J. Polym. Res.* 2026, PETG FFF con UV y agua (solo resumen) | https://ouci.dntb.gov.ua/en/works/420Ggj6V/ |
| S13 | "Experimental investigation of degradation in the marine environment of FDM-based 3D printed specimens", *IJLMM* 2026, doi 10.1016/j.ijlmm.2025.08.002 (solo resumen, DOAJ) | https://doaj.org/api/search/articles/title%3A%22degradation%20in%20the%20marine%20environment%20of%20FDM%22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 |
| S14 | Chaudhary, Li y Matos, *Results in Materials* 2023, doi 10.1016/j.rinma.2023.100381 (solo resumen, DOAJ) | https://doaj.org/api/search/articles/title%3A%22thermoplastics%20in%20seawater%22 |
| S15 | Stankevics et al., *Polymers* 2025, fluencia viscoelástica de PETG impreso | https://pmc.ncbi.nlm.nih.gov/articles/PMC12349189 |
| S16 | Martins et al., *Polymers* 2024, PLA y PETG: tracción y curvas S-N | https://pmc.ncbi.nlm.nih.gov/articles/PMC11243948/ |
| S17 | Rodrigues et al., *Polymers* 2026, fatiga de ASA, PA12, PC y PC-ABS impresos | https://pmc.ncbi.nlm.nih.gov/articles/PMC12845617/ |
| S18 | Albaşkara y Gerçekcioğlu, *Micromachines* 2026, rugosidad de PLA, PETG y ABS impresos | https://pmc.ncbi.nlm.nih.gov/articles/PMC13028808/ |
| S19 | Abas et al., *Polymers* 2023, rugosidad por cara en nylon-CF impreso | https://pmc.ncbi.nlm.nih.gov/articles/PMC10489770/ |
| S20 | Smooth-On XTC-3D, boletín técnico | https://www.smooth-on.com/tb/files/XTC3D_TB.pdf |
| S21 | West System 105/205-206-207, TDS | https://www.westsystem.com/app/uploads/2022/09/105_205-207-Combined.pdf |
| S22 | Prusa, "Watertight 3D printing part 2" | https://blog.prusa3d.com/watertight-3d-printing-part-2_53638/ |
| S23 | Hackaday 2026-05-30, ensayos de impermeabilización (resumen de Half-Baked-Research) | https://hackaday.com/2026/05/30/testing-various-ways-to-waterproof-fdm-printed-parts/ |
| S24 | Parker O-Ring Handbook ORD 5700 (copia en sealingdevices.com) | https://sealingdevices.com/wp-content/uploads/ORD-5700-Parker_O-Ring_Handbook.pdf |
| S25 | ISO 3601-2:2016, muestra pública (iTeh) | https://cdn.standards.iteh.ai/samples/69880/b3ae61dbff9a4402a74175cde66389fc/ISO-3601-2-2016.pdf |
| S26 | Trelleborg, catálogo "O-Rings and Back-up Rings" (junio 2024) | https://www.trelleborg.com/-/media/tss-media-repository/tss_website/pdf-and-other-literature/catalogs/o_ring_gb_en.pdf |
| S27 | CNC Kitchen, helicoils, insertos y tuercas embebidas en PETG | https://www.cnckitchen.com/blog/helicoils-threaded-insets-and-embedded-nuts-in-3d-prints-strength-amp-strength-assessment |
| S28 | CNC Kitchen, consejos para insertos térmicos | https://www.cnckitchen.com/blog/tipps-amp-tricks-fr-gewindeeinstze-im-3d-druck-3awey |
| S29 | PennEngineering, catálogo SI (insertos para plásticos) | https://www.pemnet.com/wp-content/uploads/sites/9/2022/06/sidata.pdf |
| S30 | Brassland, guía de corrosión del latón | https://brassland.com/resources/corrosion/ |
| S31 | Henkel, LOCTITE 243, TDS (abril 2025) | https://datasheets.tdx.henkel.com/LOCTITE-243-en_GL.pdf |
| S32 | Henkel, LOCTITE 425, TDS | https://datasheets.tdx.henkel.com/LOCTITE-425-en_GL.pdf |
| S33 | Henkel, *Loctite Design Guide for Bonding Plastics*, vol. 6 | https://www.ellsworth.com/globalassets/literature-library/manufacturer/henkel-loctite/henkel-loctite-design-guide-plastic-bonding.pdf |
| S34 | Eastman, guía de fabricación de Spectar (PETG en placa), TRS-236A | https://www.professionalplastics.com/professionalplastics/Spectar-Fabricating.pdf |
| S35 | Hackaday 2025-01-30, adhesivos para PETG (resumen del ensayo de Cosel) | https://hackaday.com/2025/01/30/comparing-adhesives-for-gluing-petg-prints/ |
| S36 | Sika, Sikaflex-291i, PDS (DK, 04-2023) | https://industry.sika.com/content/dam/dms/dk01/j/sikaflex_-291i.pdf |
| S37 | SKF, retenes HMS5 y HMSA10 | https://www.skf.com/skf/campaign/newindustrialoffers/upload/products/Radial%20Shaft%20Seals%20for%20catalogue%20gearboxes/Maximizing%20bearing%20performance.pdf |
| S38 | Boletín de Trey Bull, mantenimiento de prensaestopas | https://sites.google.com/site/treybullemlnewsletter/taking-care-of-your-boat/servicing-your-stuffing-box |
| S39 | Blue Robotics, propulsor T200 (motor inundado) | https://bluerobotics.com/store/thrusters/t100-t200-thrusters/t200-thruster-r2-rp/ |
| S40 | LAPP SKINTOP ST-M, hoja de datos (2023) | https://storage.tameson.com/asset/Products/Tameson/Electrical/Connectors,%20Cables/Wire%20And%20Cable%20Management/Cable%20And%20Mesh%20Grip/Cable%20Gland/Lapp/S-7DJU%20-%20EC000441/Image/e3tej_chr_en_2.pdf |
| S41 | Bulgin, serie 900 Buccaneer | https://www.bulgin.com/products/pub/media/import/attachments/900%20Series.pdf |
| S42 | ASSDA, inoxidable en ambiente marino | https://www.assda.asn.au/component/content/article?id=170...in-marine |
| S43 | Polymers 2026, PETG y PETG+CF expuestos a aceite mineral (PMC12986719) | https://pmc.ncbi.nlm.nih.gov/articles/PMC12986719/ |

---

## 1. Resumen ejecutivo

1. **PETG sigue siendo el material correcto para P1.** Absorbe poca agua: ~0,3 % a saturación [VERIFICADO: S11] y <1 % aun a 70 °C [VERIFICADO: S12]. Se imprime bien en la Ender-3 S1 y no requiere cerramiento.
   - **Sí pierde resistencia en agua de mar: −17 a −28 % a 30 días** [VERIFICADO: S13]. El `f_water = 0,85` de `inputs.yaml` es optimista: propongo **0,75**.
2. **Entre capas (Z) el PETG es débil y muy variable.** Según la fuente, Z vale **38 %** [VERIFICADO: S1, "interlayer adhesion" 18 ± 4 MPa contra 47 MPa en XY], 69 % [VERIFICADO: S3] u 84 % [VERIFICADO: S2] de XY. Propongo `f_z = 0,40` (hoy 0,55).
3. **Fatiga: es el hallazgo más fuerte.**
   - PETG impreso a R = 0,2 rompe en 0,8–1,9·10⁵ ciclos al **30 % de su UTS** [VERIFICADO: S16]. Extrapolado (Basquin), queda en ~8 % de la UTS a 10⁷ ciclos y ~4 % a 10⁸ [CALCULADO].
   - En P1, la frecuencia de paso de pala es de ~50 Hz: **~5·10⁷ ciclos en 300 h** [CALCULADO].
   - El `f_fatigue = 0,30` de `inputs.yaml` es **~5× no conservador**. Propongo **0,06**: las piezas impresas no deben quedar en la ruta de carga alterna.
   - *Corrección (verificación adversarial):* con las rpm actuales de `resultados/sizing_tablas.md` (1491 rpm de hélice en crucero, no 991), el paso de pala es **~75 Hz** y suma **~8·10⁷ ciclos en 300 h** [CALCULADO]. A 8·10⁷ el ajuste da **4,2 %** de la UTS, así que 0,06 queda ~1,4× por encima de la propia extrapolación; ver §A6.
4. **Temperatura.** El PETG tiene HDT de **68 °C** (Prusament y Bambu) [VERIFICADO: S1, S3] o **75 °C** (PolyLite, a 1,8 MPa) [VERIFICADO: S2]. La epoxi de laminado común (West 105/205) tiene **HDT de 48 °C** [VERIFICADO: S21].
   - Límite para PETG cargado: **50 °C**. Nada impreso debe tocar el motor ni el disipador del ESC.
5. **Con la impresora de P1 solo se pueden imprimir PETG y PETG-CF.**
   - PA6-CF y PA12-CF piden boquilla de 280–300 °C [VERIFICADO: S8, S9, S10].
   - PC pide cámara de 70–100 °C [VERIFICADO: S6] y ASA pide cerramiento [VERIFICADO: S5].
   - El PETG-CF no gana temperatura (HDT 65,7 °C) y es frágil en Z (1,9 % de elongación) [VERIFICADO: S4].
6. **Uniones roscadas.**
   - Los insertos de latón se descincifican en agua salada (Zn > ~15 %) [VERIFICADO: S30].
   - Una **tuerca A4 cautiva en bolsillo de fondo** resistió **166 kg**, más que el inserto térmico (**119 kg**) [VERIFICADO: S27]. Es más barata y de inoxidable.
   - Loctite 243 **no se recomienda sobre termoplásticos** (stress cracking) [VERIFICADO: S31].
7. **Sellado.**
   - Una superficie impresa tiene Ra/Sa de ~2–24 µm [VERIFICADO: S18, S19]. Un sello estático pide Ra ≤ 0,8 µm (Parker) o ≤ 1,6 µm (Trelleborg) [VERIFICADO: S24, S26].
   - Conclusión: **sello axial (de cara) con O-ring de 3,53 mm** en cara refrentada en el torno, o junta blanda. Evitar sellos radiales impresos: piden excentricidad ≤ 0,05 mm [VERIFICADO: S24].
8. **La cola larga de P1 no necesita ningún sello dinámico sumergido.** Bujes lubricados por agua + motor seco arriba. Solo quedan sellos estáticos de salpicadura (caja del ESC) y excluidores de arena. Es una ventaja fuerte frente al pod sumergido.

---

# PARTE A — MATERIALES

## A1. Propiedades de los candidatos (TDS de fabricante)

Probetas de los TDS: 100 % de relleno, 2 perímetros (Bambu no declara perímetros). En los de Polymaker PETG, ASA, PC, PA6-CF y PA12-CF, además, ventilador apagado [VERIFICADO: S2, S5, S6, S8, S9]. *Corregido:* en PETG-rCF08 las probetas se hicieron con ventilador al 0–50 % [VERIFICADO: S4], no apagado. ASA y PC se imprimieron con **cámara a 90 °C** [VERIFICADO: S5, S6]: esos valores **no son alcanzables** en una Ender-3 S1 abierta.

| Material (fuente) | Tg [°C] | HDT 0,45 / 1,8 MPa [°C] | Agua (condición) | σt XY [MPa] | σt Z [MPa] | Z/XY | E XY [MPa] | Boquilla [°C] | Cámara | ¿Ender-3 S1? |
|---|---|---|---|---|---|---|---|---|---|---|
| Prusament PETG (S1) | — | 68 / 68 | 0,07 % 24 h; 0,10 % 7 d (24 °C, 22 % HR) | 47 ± 2 (horizontal) | **18 ± 4** ("interlayer adhesion") | **0,38** | 1500 | 250 ± 10 | no | **Sí** |
| PolyLite PETG (S2) | 81 | 78 / 75 | 0,54 % equil. (70 % HR, 23 °C) | 50,8 ± 0,9 | 42,8 ± 2,8 | 0,84 | 2117 | 230–260 | no | **Sí** |
| Bambu PETG Basic (S3) | 69 | 71 / 68 | 0,45 % sat. (25 °C, 55 % HR) | 51 ± 1 | 35 ± 6 | 0,69 | 2780 | 230–260 | recomienda 35–50 °C (impresoras Bambu cerradas) | **Sí** |
| Fiberon PETG-rCF08 (S4) | 69,7 | 68,6 / 65,7 | 0,55 % equil. (70 % HR) | 59,8 ± 0,3 | 41,1 ± 4,1 | 0,69 | 3710 | 240–270 | no | Sí, con **boquilla endurecida** |
| Polymaker ASA (S5) | 98 | 103 / 100 | (curva; sin número en texto) | 43,8 ± 0,8 | 32 ± 1,8 | 0,73 | 2379 | 230–260 | **sí** ("Needed") | Solo con cerramiento |
| PolyLite PC (S6) | 113 | 111 / 107 | (curva) | 69,1 ± 3,0 | 52,8 ± 1,7 | 0,76 | 2497 | 250–270 | **sí, 70–100 °C** | **No** |
| Polymaker PC-PBT (S7) | 140 | 107 / 91 | (curva) | 50,4 ± 0,6 | 37,9 ± 0,3 | 0,75 | 1940 | 260–280 | **sí, 100–110 °C** | **No** |
| Fiberon PA6-CF20 seco (S8) | 74,2 | 215 / 173 | 3,3 % equil. | 109,3 ± 2,4 | 54,0 ± 5,2 | 0,49 | 8637 | **280–300** | no | **No** (hotend) |
| PA6-CF20 **húmedo** (5,3 % agua) (S8) | — | — | — | **54,7** (−50 %) | **25,5** (−53 %) | 0,47 | **2508** (−71 %) | | | |
| Fiberon PA12-CF10 seco (S9) | 55 | 131 / 105 | 1,5 % equil. | 77,4 ± 1,1 | 52,2 ± 0,8 | 0,67 | 3311 | **280–300** | no | **No** (hotend) |
| PA12-CF10 **húmedo** (2,92 % agua) (S9) | — | — | — | **71,7** (−7 %) | **42,1** (−19 %) | 0,59 | 3132 | | | |
| Epoxi West 105/205 (S21) | 54 onset / 61 último | — / **48** (118 °F) | — | 54,5 (7900 psi) | — | — | 2810 (4,08·10⁵ psi) | — | — | recubrimiento |

Notas:
- Para PA6-CF20 y PA12-CF10 los TDS piden además **recocido de 100 °C × 16 h** y boquilla endurecida. Una boquilla de latón dura **~9 h** [VERIFICADO: S8, S9; S10 solo dice "hardened nozzle"].
- "Húmedo" = sumergido 48 h a 60 °C [VERIFICADO: S8, S9]. Los porcentajes son [CALCULADO] contra el valor seco.
- Que la Ender-3 S1 llegue a ≤260 °C es dato del usuario (`inputs.yaml`). Que su boquilla de serie sea de latón es [SUPUESTO: verificar].
- La HDT de PETG varía según la marca: entre 65,7 y 75 °C a 1,8 MPa [VERIFICADO: S1–S4]. **Comprar PETG con HDT(1,8 MPa) ≥ 70 °C** declarada; PolyLite cumple (75 °C) [VERIFICADO: S2].

## A2. PETG en agua de mar o salobre: estudios

| Estudio | Exposición | Absorción | Efecto mecánico | Etiqueta |
|---|---|---|---|---|
| Moreno Nieto 2021 (S11) | Agua destilada, salmuera 28 % p/p, azúcar; 20 °C; semanal | **~0,3 %**; se estabiliza a las **7–9 semanas** (salada: semana 7) | Sin ensayos mecánicos | [VERIFICADO: S11] |
| Gama 2026 (S12, resumen) | Destilada y salina, **70 °C, 10 semanas**; UV hasta **1000 h** | **<1 %** | Baja el módulo de almacenamiento y "levemente" la Tg (plastificación **reversible**). La tracción sube un poco. Con UV, cambios moleculares menores. | [VERIFICADO: S12] |
| IJLMM 2026 (S13, resumen) | Agua de mar artificial y natural, 30 días | — | Tracción **PETG −17 a −28 %**; Nylon −31 a −44 %; ABS −15 a −25 %; PLA −26 a −35 % | [VERIFICADO: S13] |
| Chaudhary 2023 (S14, resumen) | Agua de mar a temperatura elevada (acelerado); Nylon, ABS, PLA, PCTG, PETG, ASA | Las estructuras impresas tienen **difusividad "extremadamente alta" frente al material macizo** | Las propiedades bajan en todos; la rigidez cae en proporción a la masa absorbida | [VERIFICADO: S14] |

Lectura para P1:
- Una pieza impresa se satura en semanas, no en años (porosidad) [VERIFICADO: S11, S14]. Hay que **diseñar con propiedades saturadas desde el día 1**.
- S12 y S13 discrepan en la pérdida de resistencia. Para diseño tomo la peor: **−28 % → f_water = 0,72 ≈ 0,75** [CALCULADO].
  - *Corrección (verificación):* redondear 0,72 a 0,75 **no** es tomar la peor; es ~4 % no conservador. El peor caso estricto de S13 es **0,72**. Si se mantiene 0,75, que sea una decisión explícita.
- Hay que validarlo con probetas propias (§A9.4).

**UV.** PETG mantuvo la estructura con hasta 1000 h de UV de laboratorio [VERIFICADO: S12]. ASA se vende por su "improved weather resistance… UV resistance" [VERIFICADO: S5]. La equivalencia entre esas 1000 h y temporadas reales en Dinamarca no está establecida [SUPUESTO]. Para piezas al sol: **colores claros**, inspección anual.

## A3. Anisotropía (Z frente a XY)

| Fuente | Z/XY | Condición |
|---|---|---|
| Prusament (S1) | **0,38** (18/47) | Ensayo propio de adhesión entre capas. Es el más pesimista. |
| Bambu PETG Basic (S3) | 0,69 (35/51); flexión 0,75; impacto 0,31 (10,5/34,2) | Probeta Z con 100 % de relleno |
| Polymaker PETG (S2) | 0,84 (42,8/50,8); elongación Z 3,3 % contra 8,4 % | Ventilador apagado, 2 perímetros |
| Stankevics 2025 (S15) | **0,45** **en el plano**, entre cordones (22,48/50,44 MPa, dispersión ±4,61) | Relleno unidireccional, 0,1 mm, 235 °C |
| Polymaker PETG-rCF08 (S4) | 0,69; elongación Z **1,9 %** | La fibra empeora la ductilidad en Z |

- **Propuesta: `f_z = 0,40`** [ESTIMADO: entre el mínimo de S1 (0,38) y el de S15 (0,45)]. La Ender-3 S1 imprime abierta y con ventilador, y las piezas de P1 son grandes (capas que se enfrían más que en una probeta).
- La anisotropía también existe **dentro de la capa** entre cordones [VERIFICADO: S15]. Por eso, en piezas cargadas: ≥ 6–8 perímetros siguiendo el contorno de carga y relleno ≥ 60 % [ESTIMADO].

## A4. Temperatura de servicio

- HDT a 1,8 MPa: Prusament 68 °C, Bambu 68 °C, PolyLite 75 °C, PETG-rCF08 65,7 °C [VERIFICADO: S1–S4]. El agua baja algo la Tg [VERIFICADO: S12].
- **Propuesta para `t_service_max_c`:** 50 °C en piezas de PETG **con carga**; 60 °C en tapas sin carga [ESTIMADO: HDT mínima 65,7–68 °C menos ~15–18 K de margen por creep y humedad]. Hoy está en 60 °C; bajar a 50 °C.
- **Cerca del motor y del ESC.**
  - El estator y la campana de un outrunner pueden pasar de 60–80 °C con carga sostenida [ESTIMADO: memoria técnica, no verificado].
  - Soporte de motor de **aluminio**, separadores y arandelas aislantes.
  - Que **ninguna pieza de PETG toque la campana, la brida del motor ni el disipador del ESC**.
  - Medir con el termopar del multímetro en la primera prueba de 2 h.
- **Al sol.** Una superficie oscura puede pasar de 60 °C al sol de verano [ESTIMADO: memoria técnica, no verificado]. Usar PETG blanco, gris claro o natural en la abrazadera de espejo y los soportes.
- **Epoxi como recubrimiento:** la West 105/205 tiene HDT de 48 °C y Tg última de 61 °C [VERIFICADO: S21]. Sirve para sellar o alisar piezas frías; **no** para piezas calientes.
- **f_temp** (resistencia relativa a 23 °C) [ESTIMADO: memoria técnica de copoliésteres amorfos, no verificado]:
  - 0,85 hasta 40 °C (el valor de `inputs.yaml` es razonable);
  - 0,70 hasta 50 °C;
  - no usar con carga por encima de 50 °C.

## A5. Fluencia (creep)

Datos de S15 (PETG, 21 °C, 39 % HR) [VERIFICADO: S15]:
- Al **50 % de la resistencia** (25 MPa en X), el creep a 5 h es "roughly 5% of the sample elastic strain", y "In 20 h, this strain had doubled" (~10 %).
- Al **70 %** (35 MPa), llega al **25 % a 5 h en X** (7 % en Y) y sube a **30 % (X) y 8 % (Y)**: comportamiento no lineal. *Corregido:* la versión anterior atribuía la duplicación a 20 h al caso del 70 %; en S15 corresponde al caso del 50 %.
- Hay deformación plástica por encima de ~0,1 % de creep en X y ~0,05 % en Y.

Extrapolar a cargas de meses, mojado y a 30–40 °C:
- **`f_creep = 0,35`** para carga sostenida >100 h [ESTIMADO: el umbral no lineal de S15 es ~50 % a 21 °C y en seco; le resto margen por agua (S12) y temperatura]. Hoy está en 0,50.
- **Precarga de tornillos sobre PETG.** El plástico fluye y la precarga se pierde. En las uniones de la abrazadera de espejo y del cardán, usar **casquillos limitadores de compresión metálicos**: tubo de inox o aluminio atravesando el plástico, con el tornillo apretando metal contra metal [ESTIMADO: práctica estándar en plásticos].
  - Eastman recomienda arandelas para repartir la carga y no apretar de más [VERIFICADO: S34].

## A6. Fatiga a 10⁷–10⁸ ciclos

**Ciclos en P1** [CALCULADO]:
- Hélice a 991 rpm en crucero × 3 palas = **49,6 Hz**.
- Son **3,6·10⁵ ciclos por salida de 2 h** y **5,4·10⁷ en 300 h** de vida.
- Motor a ~2970 rpm (49,6 Hz de desbalanceo, relación 3:1). Engrane de correa: ~790 Hz.
- Fuente: rpm de `resultados/sizing_tablas.md`.
- *Corrección (verificación, contra `sizing_tablas.md` del 2026-10-01 14:07):* hoy la tabla da **1491 rpm** de hélice en crucero y correa **20T:40T = 2,00**. Recalculado [CALCULADO]:
  - paso de pala **74,6 Hz** (3 palas, `inputs.yaml` Z = 3 [ESTIMADO]);
  - **5,4·10⁵ ciclos por salida de 2 h** y **8,1·10⁷ en 300 h**;
  - motor a ~2980 rpm (49,7 Hz de desbalanceo); engrane de correa con polea de 20 dientes: **~990 Hz**.

**Datos:**

| Fuente | Material y condición | Resultado |
|---|---|---|
| Martins 2024 (S16) | PETG FFF a 45°, R = 0,2, 7 Hz, boquilla **215–220 °C** (baja), UTS 32,9 MPa | σmax 60 % → 1,2–1,5·10⁴ ciclos; 45 % → 1,7–4,1·10⁴; **30 % (10,2 MPa) → 0,8–1,9·10⁵** [VERIFICADO: S16] |
| Rodrigues 2026 (S17) | FFF en Stratasys, R = 0,05, 10 Hz, límite = **runout a 10⁶** | ASA **25 %·σR (8 MPa)**; PA12 17 % (7,4 MPa); PC-ABS 15 % (4,7 MPa); **PC 7 % (3,6 MPa)** [VERIFICADO: S17] |

**Ajuste de Basquin a S16** [CALCULADO: medias geométricas de los tres niveles]:
- σmax = 367·N^−0,306 MPa. (*Corregido:* decía 362. El ajuste por mínimos cuadrados log-log sobre las medias geométricas 13 290 / 29 123 / 124 158 ciclos de la Tabla 2 de S16 da A = 367; la tabla de abajo ya usaba ese valor.)
- Nota: en S16 los niveles 20,4 / 15,3 / 10,2 MPa son el 60 / 45 / 30 % de ~34 MPa, no de la UTS de 32,9 MPa (que es de probetas a 0°; las de fatiga son a ±45°) [VERIFICADO: S16, Tablas 1 y 2]. Los "% de la UTS" de abajo pueden estar ~3 % altos.

| N | σmax PETG (S16, UTS 32,9) | % de la UTS | Escalado a UTS 45 MPa | σa (R = 0,2) |
|---|---|---|---|---|
| 10⁶ | 5,3 MPa | 16 % | 7,2 MPa | 2,9 MPa |
| 10⁷ | 2,6 MPa | 8 % | 3,6 MPa | 1,4 MPa |
| 10⁸ | 1,3 MPa | 4 % | 1,8 MPa | 0,7 MPa |

- El 16 % de la UTS a 10⁶ coincide con el rango de 7–25 % que S17 mide en otros termoplásticos impresos. Es un **cruce de verificación razonable** [CALCULADO].
- Extrapolar 2,7 décadas más allá del último dato es incierto. Un codo de fatiga podría dar algo mejor, pero no hay datos de PETG impreso a 10⁷–10⁸ [SUPUESTO].
- **Propuesta: `f_fatigue = 0,06`** (σmax/UTS para 10⁸ ciclos, R entre 0 y 0,2) [ESTIMADO: entre el 4 % (10⁸) y el 8 % (10⁷) del ajuste]. Hoy está en 0,30.
  - *Corrección (verificación):* con 8,1·10⁷ ciclos (rpm actuales), el ajuste da σmax = 1,39 MPa = **4,2 %** de la UTS [CALCULADO]. Para ser coherente con la vida real, `f_fatigue` debería estar en **~0,045**; 0,06 es ~1,4× más alto que la propia extrapolación.
- **Regla de diseño:** con agua y temperatura, **σa ≤ 0,5 MPa en XY y ≤ 0,2 MPa a través de capas** [CALCULADO: 45 × 0,06 × 0,75 × 0,85 = 1,7 MPa de σmax → σa ≈ 0,77 MPa → /1,5 = 0,52 MPa; × f_z 0,40 = 0,21 MPa].
  - Aclaración: σa = 0,45·σmax supone **R = 0,1** (punto medio de 0–0,2). Con R = 0,2, σa = 0,4·σmax = 0,69 MPa → 0,46 MPa (XY) y 0,18 MPa (Z) [CALCULADO]. Con `f_fatigue` = 0,045, quedan ~0,35 MPa (XY) y ~0,14 MPa (Z) [CALCULADO].

**Consecuencia práctica.** Ninguna pieza impresa puede ser la ruta de carga alterna:
- de la hélice al espejo (tubo, cardán, pivote);
- de la correa (tensión fluctuante en el soporte del motor);
- del desbalanceo del motor.

Esas rutas van en **aluminio o inox**. Lo impreso queda para carenados, tapas, cajas y el protector de hélice. Y aun así el protector recibe pulsos de presión a ~75 Hz (antes decía ~50 Hz; ver corrección de rpm arriba) cerca de las puntas. R02 y R03 documentan una hélice de PETG, ~4 meses en agua de mar, a la que se le **fisuró una pala al desmontarla** para inspección. Por eso el protector se trata como **consumible inspeccionable**: paredes ≥ 4 mm, fijación con flejes metálicos e inspección mensual de fisuras [ESTIMADO].

## A7. Factores de reducción propuestos (actualizar `inputs.yaml`)

| Factor | `inputs.yaml` hoy | **Propuesto** | Base |
|---|---|---|---|
| f_water | 0,85 | **0,75** (peor caso estricto: 0,72) | −17 a −28 % a 30 días en agua de mar [VERIFICADO: S13]; saturación en semanas [VERIFICADO: S11, S14] |
| f_temp (≤40 °C) | 0,85 | 0,85 (≤40 °C); **0,70 (≤50 °C)** | [ESTIMADO: memoria técnica, no verificado]; HDT 65,7–75 °C [VERIFICADO: S1–S4] |
| f_process | 0,80 | 0,80 | [ESTIMADO]; validar con probetas propias (§A9.4) |
| f_creep (>100 h) | 0,50 | **0,35** | Creep no lineal desde ~50 % de la resistencia a 21 °C [VERIFICADO: S15] + agua y temperatura [ESTIMADO] |
| f_fatigue (10⁷–10⁸) | 0,30 | **0,06** (~0,045 con 8·10⁷ ciclos; ver §A6) | Basquin sobre S16 [CALCULADO]; contraste con S17 [VERIFICADO] |
| f_z | 0,55 | **0,40** | Z/XY = 0,38 (S1), 0,45 en el plano (S15), 0,69 (S3), 0,84 (S2) |
| t_service_max_c | 60 | **50** (con carga) | §A4 |
| sigma_t_xy_mpa | 45 | 45, **solo si la probeta propia da ≥ 40** | TDS 47–51 [VERIFICADO: S1–S3]; impreso frío da 32,9 [VERIFICADO: S16] |
| sigma_t_z_mpa | 25 | **18** | 18 ± 4 [VERIFICADO: S1] |

**Tensiones admisibles resultantes, PETG** [CALCULADO: 45 MPa × f_water 0,75 × f_temp 0,85 × f_process 0,80 = 23,0 MPa característica, en XY]:

| Caso | XY sin FS | XY con FS 3 | Z sin FS | Z con FS 3 |
|---|---|---|---|---|
| Pico de corto plazo (golpe de kick-up, maniobra) | 23,0 | **7,7** | 9,2 | **3,1** |
| Sostenida >100 h (precarga, peso) | 8,0 | **2,7** | 3,2 | **1,1** |
| Alterna a 10⁸ ciclos (σa) | 0,77 | **0,5** (FS 1,5) | 0,31 | **0,2** (FS 1,5) |

En fatiga el FS 1,5 ya va sobre un límite inferior extrapolado. Aplicarle FS 3 es redundante [SUPUESTO: lo decide quien diseña]. Con los factores actuales, la sostenida con FS 3 en XY daba 4,3 MPa: los nuevos son **~40 % más bajos** [CALCULADO].

## A8. ¿Qué material para qué pieza de P1?

| Pieza | Material | Por qué |
|---|---|---|
| Protector de hélice y patín | **PETG** claro, paredes ≥ 4 mm, 100 % de relleno en fijaciones; ASA si se hace un cerramiento | Consumible. Fatiga a ~75 Hz (§A6, rpm corregidas). Fisuras documentadas en R02 y R03. |
| Caja del ESC | PETG + **tapa o placa base de aluminio** (disipador) + sello axial (§B3) | El ESC calienta; el PETG no debe tocar el disipador (§A4) |
| Tapa de correa y cubierta del motor | PETG o ASA, **sin sellar, con drenaje** | Salpicadura; un sello atrapa agua (R02 §lecciones: "drenaje y no solo sellos") |
| Soporte de motor, cardán, abrazadera de espejo, pivote de kick-up | **Aluminio e inox**. Lo impreso solo como carenado o separador **a compresión** con limitadores metálicos | Fatiga (§A6) y creep (§A5) |
| Bujes del tubo (en agua) | **POM-C torneado** (decisión ya tomada en `inputs.yaml`), no impreso | Desgaste con arena; tolerancia de buje [ESTIMADO] |
| Mango del timón | PETG, 8 perímetros [SUPUESTO] | Cargas humanas estáticas; verificar con FS 3 |
| Piezas rígidas no calientes (placas, nervios) | PETG-CF (solo con boquilla endurecida) | +75 % de módulo XY (3710 contra 2117 MPa) [VERIFICADO: S2, S4], sin ganancia térmica y frágil en Z |
| Nylon-CF | **Descartado** con esta impresora | Pide 280–300 °C [VERIFICADO: S8, S9]. El PA6-CF pierde 50–71 % mojado [VERIFICADO: S8]. El PA12-CF10 sería el mejor en agua (−7 % XY mojado [VERIFICADO: S9]) **solo si se tercerizara**. |
| PC / PC-PBT | **Descartados** | Cámara de 70–110 °C [VERIFICADO: S6, S7]; PC con fatiga de solo 7 % de σR [VERIFICADO: S17]; Sikaflex prohíbe PC (stress cracking) [VERIFICADO: S36] |

## A9. Recubrimiento epoxi

### A9.1 Datos

| Producto | Datos verificados | Uso en P1 |
|---|---|---|
| Smooth-On XTC-3D (S20) | Mezcla 2A:1B en volumen; 350 cps; vida útil 10 min; curado 3,5 h en capa fina; **Shore 80D**; "works with PLA, ABS, **PetG**"; "does not melt plastic"; 28,3 g cubren 651 cm² a 0,4 mm [VERIFICADO: S20] | Alisar caras de sello antes de lijar; capa < 0,4 mm |
| West System 105/205 (S21) | 54,5 MPa; elongación 3,4 %; **HDT 48 °C**; Tg onset 54 °C, última 61 °C; "superior moisture barrier" (afirmación del fabricante) [VERIFICADO: S21] | Impregnación y barrera en piezas frías; **no** cerca del motor o del ESC |
| 3M Scotch-Weld DP-100 | Eastman lo recomienda para pegar Spectar (PETG) consigo mismo [VERIFICADO: S34] | Pegado estructural PETG-PETG |
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

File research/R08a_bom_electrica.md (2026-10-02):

# R08a — Sourcing BOM eléctrica con envío a Dinamarca

Proyecto P1 (cola larga eléctrica, jon boat < 2,5 m, Als Fjord). **Fecha de consulta de todos los precios: 2026-10-01.**
Etiquetas: **[VERIFICADO: url]** = página abierta en esta sesión y el dato está ahí · **[ESTIMADO: base]** · **[SUPUESTO]** · "buscar: …" = no se pudo abrir.
Complementa R06 (arquitectura eléctrica y seguridad); acá solo producto, tienda, precio y lo que el producto concreto cambia en el diseño.

---

## 0. Bases de compra (impuestos, cambio, logística)

| Dato | Valor | Fuente |
|---|---|---|
| Cambio BCE 2026-09-30 | 1 EUR = **1,1355 USD** = **7,4755 DKK** = 0,85463 GBP → 1 USD = 0,8807 EUR = 6,58 DKK | [VERIFICADO: https://www.ecb.europa.eu/stats/eurofxref/eurofxref-hist-90d.xml] (el XML diario ya muestra 2026-10-01: 1,1298 USD / 7,4758 DKK; diferencia < 0,5 %, no cambia totales) |
| IVA DK | Reichelt DK muestra precios *"incl. 25% VAT"* | [VERIFICADO: https://www.reichelt.com/dk/en/shop/product/dc_dc_converter_r78hb_9-72_vin_single_5_vout_500_ma_sip-3-159167] |
| Compras fuera de la UE | *"If you buy goods online from outside the EU, VAT, customs and excise duty is always due."* | [VERIFICADO: https://europa.eu/youreurope/citizens/consumers/shopping/vat/index_en.htm] |
| Flipsky (CN) | *"The product price and shipping cost do not include tariffs"*; DHL 5–9 días, correo/4PX 7–25 días; despacho 3–7 días hábiles. (La página *about-tariffs* ofrece *"We can declare a low price according to your requirements"*: **no hacerlo**, es fraude aduanero.) Ni Flipsky ni este archivo incluyen el **arancel aduanero** (además del IVA) ni la tasa de despacho del courier → buscar: "TARIC 8501 32 duty rate" [ESTIMADO: ~2–3 % sobre el motor, memoria técnica, no verificado]. | [VERIFICADO: https://flipsky.net/pages/faqs] · [VERIFICADO: https://flipsky.net/pages/about-tariffs] |
| Flipsky costo de envío | No publicado (*"ship in 2-3 working days"* y nada más) → buscar: "Flipsky DHL shipping cost Denmark checkout"; uso **45 EUR** [ESTIMADO: memoria técnica, no verificado] | [VERIFICADO: https://flipsky.net/policies/shipping-policy] |
| Maytech (CN) | *"Shipping time by DHL or UPS is fast, normally 3-7 days"*; sin stock: 30–40 días | [VERIFICADO: https://maytech.cn/products/brushless-hall-sensor-motor-mto6374-170-ha-c] |
| LiTime DE | *"Kostenloser Versand für alle Bestellungen in die EU"* (excepto Chipre, Malta, Irlanda, islas pequeñas); *"Alle unsere Produkte werden aus dem deutschen Lager versandt"*; 1–2 + 2–7 días hábiles | [VERIFICADO: https://www.litime.de/policies/shipping-policy] |
| Power Queen DE | Envío *"kostenlos innerhalb der gesamten EU (außer Griechenland und Inseln)"*, 3–7 días hábiles a otros países UE | [VERIFICADO: https://www.ipowerqueen.de/products/power-queen-lifepo4-24v-50ah-smart-niedertemperatur-trolling-motor-batterie] |
| Variantes "0 % MwSt." en LiTime/Power Queen | Solo aplican a Alemania (tasa 0 % FV); para DK usar el precio normal con IVA | [VERIFICADO: páginas LiTime/PowerQueen arriba] |
| AliExpress (fallback) | Precios mostrados en EUR con región DK; IVA UE cobrado en checkout [ESTIMADO: régimen IOSS ≤ 150 EUR, no verificado en la página] | [VERIFICADO: búsquedas aliexpress.com citadas abajo] |
| No accesibles en esta sesión | hobbyking.com (403), svb24.com/svb.de (403), conrad.de (403), amazon.de (503), makerbase3d.com (captcha), flipsky.eu (sin respuesta) | — |

---

## 1. Motor BLDC outrunner (seco, sobre el agua)

| Modelo | KV | P máx | I máx | Eje | Peso | Tensión | Precio (2026-10-01) | Fuente |
|---|---|---|---|---|---|---|---|---|
| **Flipsky 6374 Battle Hardened** (hall: [NO VERIFICADO: la página de flipsky.net no menciona sensor/hall; solo revendedores de AliExpress dicen "Sensored"]) | 140/170/190 | 3500 W; 8 Nm | 85 A | 8 mm redondo o 10 mm D (108 mm / 99 mm = largo de los planos, no del eje) | **0,98 kg** | 3–12S | **87 USD** s/polea (93 con polea) = 76,6 EUR | [VERIFICADO: https://flipsky.net/products/flipsky-bldc-belt-motor-battle-hardened-6374-140kv-170kv-190kv-3500w-for-electric-skateboard] |
| Flipsky 6384 Battle Hardened | 140/170/190 | 4000 W, 9 Nm | 95 A | 8 mm (30 mm) / 10 mm / 10 mm D | 1,3 kg | 4–14S; R 0,05 Ω; 14 polos; imán N42SH | 113 USD s/polea = 99,5 EUR | [VERIFICADO: https://flipsky.net/products/flipsky-bldc-belt-motor-battle-hardened-6384-140kv-170kv-190kv-4000w-for-electric-skateboard] |
| Flipsky 7070 Battle Hardened | 110/140/170 | 2200 W nominal / 4200 W | 100 A | 10 mm redondo o D | 1,08 kg | 6–18S; **cable TEMP incluido** (blanco) | 101 USD s/polea = 89,0 EUR | [VERIFICADO: https://flipsky.net/products/flipsky-sensored-outrunner-brushless-dc-motor-battle-hardened-7070-110kv-140kv-170kv-4200w] |
| Maytech MTO6374-170-HA-C (sealed "splashproof", hall) | 170/190 (110 a pedido 94,5 USD) | 3550 W | 65 A (60 A nominal) | 8 mm × 26 mm | buscar: "MTO6374-HA-C weight" | 3–12S (12–50 V) | 82,40 USD = 72,6 EUR | [VERIFICADO: https://maytech.cn/products/brushless-hall-sensor-motor-mto6374-170-ha-c] |
| Maytech MTO6374-G (sensorless) | 90/170/200/330 | 3550 W | 65 A | 8 mm | **785 g**; R 0,0402 Ω | 2–12S | 86,80 USD (90 KV: 100,90 USD) | [VERIFICADO: https://maytech.cn/products/brushless-sensorless-motor-mto6374-190-g] |
| Fallback UE: Flipsky 6374 140KV en AliExpress | 140 | 3500 W | — | — | — | — | **94,69 EUR** (item 4000966919617, 66 vendidos) | [VERIFICADO: https://www.aliexpress.com/w/wholesale-flipsky-6374-motor.html] |
| *(agregado en verificación)* Flipsky 6374 **Waterproof** 140KV "for Surfing Boat Underwater Thruster" (AliExpress) | 140 | 3600 W (título) | — | — | — | — | 111,69 EUR (94 vendidos); otras ofertas 129,69–131,39 | [VERIFICADO: https://www.aliexpress.com/w/wholesale-flipsky-6374-motor.html] — specs no abiertas |
| *(agregado en verificación)* Flipsky Waterproof 6384 140KV 4400W (flipsky.net) | 140 | 4400 W (título) | — | — | — | — | 136 USD | [VERIFICADO listado: https://flipsky.net/search/suggest.json?q=6384&resources[type]=product&resources[limit]=10] — specs no abiertas |

Notas: (a) Flipsky vende como repuesto *"3pcs 10x19x5mm NMB Japan Steel Deep Groove Ball Bearing 6800zz/6900zz for flipsky 63 series motor"* a 4,50 USD; que sean los rodamientos **de serie** es inferencia [ESTIMADO: inferido del repuesto, no dicho en la ficha del motor] → cambiar a inox/híbrido según R06 [VERIFICADO listado/precio: https://flipsky.net/search/suggest.json?q=6384&resources[type]=product&resources[limit]=10]. (b) No hay fuente UE de motores 63xx–70xx con link abierto (HobbyKing EU 403) → buscar: "Turnigy SK8 6374 149KV EU warehouse".

---

## 2. ESC VESC 75 V / 100 A

| Modelo | V | I cont./pico | BEC | Cables | FW / advertencia | Tamaño | Precio | Fuente |
|---|---|---|---|---|---|---|---|---|
| **Flipsky 75100 V2.0** (botón o llave) | 14–84 V (4–20S) | 100 A / 250 A | **5 V @ 1 A** | 12 AWG | FW 5.02; *"Phase filter needs to be turned off for firmware 5.03 or newer"*; entradas PPM, ADC, NRF, UART | 103×58×24 mm | **88 USD** (botón) / 92 USD (llave) | [VERIFICADO: https://flipsky.net/products/flipsky-75100-v2-0-with-aluminum-pcb-with-power-key-switch-button-based-on-vesc-for-electric-skateboard-electric-scooter-ebike-speed-con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] |
| Flipsky 75100 Pro | 14–84 V | 100 A / ráfaga 120 A | 5 V @ 1,5 A | **10 AWG** | *"Phase filering is not available… turn off the phase filter"*; Bluetooth integrado | 103×58×27,7 mm | 89 USD | [VERIFICADO: https://flipsky.net/products/flipsky-75100-pro-with-aluminum-pcb-based-on-vesc-for-electric-skateboard-electric-scooter-ebike-speed-controller] |
| Flipsky 75100 Pro V2.0 | — | — | — | — | — | — | 98 USD | [VERIFICADO: https://flipsky.net/search/suggest.json?q=75100%20pro&resources[type]=product&resources[limit]=10] (listado; la URL original con q=thumb throttle no corresponde) |
| *(agregado en verificación)* **Flipsky 75100 With Aluminum PCB** | 14–84 V (4–20S) | 100 A / ráfaga 120 A | **5 V @ 1,5 A** | 12 AWG | phase filter: desactivar; PPM, ADC, NRF, UART | 103×58×18,5 mm (+5,9 USB) | **73 USD** sin caja / 77 caja alu / 106 caja refrigerada por agua | [VERIFICADO: https://flipsky.net/products/flipsky-75100-with-aluminum-pcb-based-on-vesc-for-electric-skateboard-electric-scooter-ebike-speed-controller] |
| *(agregado en verificación)* Flipsky 75100 75V 100A Single | 14–84 V | 100 A / 120 A | 5 V @ 1 A | 12 AWG | PPM, ADC, NRF, UART; limitar corriente absoluta < 200 A | 85×50,7×33,8 mm | **65 USD** | [VERIFICADO: https://flipsky.net/products/flipsky-75100-75v-100a-single-esc-based-on-vesc-for-electric-skateboard-electric-scooter-ebike-speed-controller] |
| Makerbase VESC 75100 (AliExpress) | 75 V | 100 A | — | — | — | — | 63,99–65,69 EUR; V2 alu-PCB 122,69 EUR | [VERIFICADO: https://www.aliexpress.com/w/wholesale-makerbase-vesc-75100.html] |
| Flipsky 75100 en AliExpress | — | — | — | — | — | — | ~~59,99 EUR ("Flash deal", 486 vendidos)~~ [NO VERIFICADO: no aparece en la re-consulta; el Flipsky 75100 single más barato hoy es 89,39 EUR; un clon "HOEYI 75100" 62,39 EUR/388 vendidos] / V2.0 114,39 EUR (93 vendidos) | [VERIFICADO: https://www.aliexpress.com/w/wholesale-flipsky-75100.html] |

Reino Unido (escooter-parts.co.uk: 75100 V2.0 127,99 GBP) = fuera de UE → IVA de importación otra vez; no conviene [VERIFICADO precio: https://escooter-parts.co.uk/search/suggest.json?q=75100&resources[type]=product&resources[limit]=10].

---

## 3. Corte de energía: antichispa, contactor, kill switch, desconectador

| Ítem | Producto | Dato clave | Precio | Fuente |
|---|---|---|---|---|
| Antichispa | Flipsky Antispark Switch Pro V3.0 | 3–14S (12–60 V); 100 A cont. con alu PCB/caja, 60 A con disipador; LED 16 mm; *"DO NOT power on switch without the LED button connected"* | 33 USD (disipador) / 43 (alu PCB) / **48 USD (caja alu)** | [VERIFICADO: https://flipsky.net/products/flipsky-antispark-switch-pro-with-aluminum-pcb-case-200a-for-electric-skateboard-ebike-scooter-robots] |
| Antichispa (UE fallback) | Flipsky Antispark Pro V3.0 en AliExpress | — | 33,99 EUR | [VERIFICADO: https://www.aliexpress.com/w/wholesale-flipsky-antispark-switch.html] |
| Llave manual barata | Amass **XT90-S** (par) | resistencia integrada de precarga; 45 A cont. / 90 A corto | 3,69 EUR | [VERIFICADO: https://www.rotorama.com/product/xt90s-antispark-konektor-par] |
| **Kill switch cordón (fail-safe)** | Watski "Dødmands kontakt universal" (SKU 203517) | *"M-polerne har gennemgang når sikkerhedskontakten er isat"* (cerrado con clip = fail-safe); polos C cerrados sin clip; **12 V – 15 A** | **74 DKK** | [VERIFICADO: https://www.watski.dk/Ddmands-kontakt-universal-110CP] |
| Kill switch alternativo | Osculati "Nødstopafbryder + sikkerhedsnøgle" | *"kan åbne og lukke kredsløbet afhængigt af tilsluttede terminaler"*; rating no publicado | 129 DKK (bestillingsvare) | [VERIFICADO: https://www.watski.dk/nodstopafbryder-sikkerhedsnogle-1b1Vj] |
| Kill switch con flotador | Osculati con llave y flotador | idem, flotante | 139 DKK | [VERIFICADO: https://www.watski.dk/nodstopafbryder-med-sikkerhedsnoegle-og-flyder-1b1Vp] |
| Solo cordón (sin interruptor) | Biltema Dødemandsgreb 135 cm | espiral 135 cm; *"af sluttende type til udenbordsmotorer"* | 74,90 DKK | [VERIFICADO: https://www.biltema.dk/baad/sikkerhedsudstyr/redningsliner/dodemandsgreb-135-cm-2000040861] |
| Contactor DC servicio continuo | Albright SW80 (recomendado en R06) | — | buscar: "Albright SW80 24V coil price EU"; [ESTIMADO: 60–100 EUR, memoria técnica] | — |
| Relé de bajo costo (NO es contactor) | FREI FRC3 A 24 (Reichelt) | bobina 24 V DC, **320 Ω** (→ 75 mA [ESTIMADO: 24 V/320 Ω]); AgSnO2; *"Max. switching voltage: 75 VDC – Max switching current: 70 A"* pero *"Contacts: 1 NOC, **40 A**"*; Faston 6,35/9,5 mm (no admite 16 mm² directo); tipo de carga/vida de corte DC no publicados | 3,26 EUR | [VERIFICADO: https://www.reichelt.com/dk/en/shop/product/70a_high-current_relay_frc3_24_v_1_n_o_contact-79404] |
| Descartado | Zettler AZ160-1AE-24D | relé de PCB, 60 A, 480 V **AC**; corte DC no especificado | 3,73 EUR | [VERIFICADO: https://www.reichelt.com/dk/en/shop/product/high-current_relay_1x_no_60_a_24_v_dc-415707] |
| Descartado | Lewmar kontaktor ensrettet 24 V | contactor de molinete/cabrestante (servicio intermitente [ESTIMADO: uso típico de molinete]) | 669 DKK | [VERIFICADO: https://www.watski.dk/kontakt-enkelt-1224V-116Ft] |
| **Desconectador de batería** | Biltema Hovedafbryder AFD ON/OFF (art. 25-8849) | **12–48 V DC**; 275 A cont., 455 A 5 min, 1250 A 10 s; M10; IP65; bornes de cobre estañado; llave removible | **159 DKK** | [VERIFICADO: https://www.biltema.dk/baad/eludstyr/elinstallationer-til-bade/stromafbrydere/hovedafbryder-afd-onoff-2000063980] |
| Desconectador alt. | 1852 hovedafbryder 275 A 12–48 V | Ø 52 mm de montaje | 180 DKK | [VERIFICADO: https://www.watski.dk/1852-hovedafbryder-275Amp-12-48-vdc-11ECI] |
| Desconectador alt. | Blue Sea hovedafbryder 300 A | 300 A cont., 500 A 5 min, 1500 A 10 s; **máx. 48 V** | 358 DKK | [VERIFICADO: https://www.watski.dk/blue-sea-hovedafbryder-300-ah-11Eiy] |
| Desconectador alt. | Compass24 "Hovedafbryder til batteri 275 A" | hasta 50 V; 275 A cont.; 1250 A máx. | 295 DKK | [VERIFICADO: https://www.compass24.dk/hovedafbryder-til-batteri-275-a-289021/275-5-6x5-6x7-4-1250] |

---

## 4. Batería LiFePO4 con BMS

| Producto | Config. | Energía | BMS cont. / pico | Peso | IP | Frío | Precio | €/kWh | Fuente |
|---|---|---|---|---|---|---|---|---|---|
| **LiTime 24V 50Ah TM Bluetooth** | 8S (25,6 V) | 1280 Wh | **50 A** / 250 A 1 s | 21,15 lb (9,6 kg) | IP65 | no carga < 0 °C, no descarga < −20 °C | **309,99 EUR** (envío gratis UE) | 242 | [VERIFICADO: https://www.litime.de/products/24v-50ah-bluetooth-lithium-batterie-fur-elektromotor-boote] · specs [VERIFICADO: https://www.litime.com/products/litime-24v-50ah-tm-bluetooth-lifepo4-battery] |
| Power Queen 24V 50Ah Smart | 25,6 V | 1280 Wh | 50 A; *"60A@30mins"*; carga máx. 50 A; 28,8 ± 0,4 V; R int. ≤ 40 mΩ; máx. 4P2S | buscar | IP65 | carga 0…50 °C (*"– 50°C / 32°F – 122°F"*); protección de baja T con **reanudación automática a 5 °C** (no corte a 5 °C); descarga −20…60 °C | 329,99 EUR (con cargador 29 V 20 A: 449,98) | 258 | [VERIFICADO: https://www.ipowerqueen.de/products/power-queen-lifepo4-24v-50ah-smart-niedertemperatur-trolling-motor-batterie] — 26,0×16,8×21,0 cm, bornes M8 |
| 2× LiTime 12V 50Ah TM | 2S → 25,6 V | 1280 Wh | 1,2C (60 A) 30 min c/u | 2 × ~5,1 kg (peso de envío 5110 g) | — | 0 °C / −20 °C | 2 × 189,99 = 379,98 EUR | 297 | [VERIFICADO: https://www.litime.de/products/12v-50ah-bluetooth-lithium-batterie-fur-elektromotor-boote-zuverlassige-power] (admite 4P4S) |
| 2× Power Queen 12V 50Ah | 2S | 1280 Wh | 50 A c/u | 2 × 5,29 kg | IP65 | — | pack-2 **316,78 EUR** | 247 | [VERIFICADO: https://www.ipowerqueen.de/products/power-queen-12v-50ah-lifepo4-batterie-eingebautes-50a-bms] — 19,5×16,6×17,2 cm |
| **2× Power Queen 12V 100Ah** | 2S | **2560 Wh** | **100 A** c/u | 2 × ~11 kg (peso de envío) | buscar | — | pack-2 **475,18 EUR** | **186** | [VERIFICADO: https://www.ipowerqueen.de/products/power-queen-12-v-100-ah-lifepo4-deep-cycle-batterie] (hasta 4P4S) |
| 2× LiTime 12V 100Ah TM | 2S | 2560 Wh | buscar | 2 × ~10 kg (envío 10050 g) | — | 0 °C / −20 °C | 2 × 259,99 = 519,98 EUR | 203 | [VERIFICADO: https://www.litime.de/products/12v-100ah-lifepo4-batterie-elektromotoren-tieftemperaturschutz-tm] |
| LiTime 36V 50Ah TM (12S, recomendado por R06) | 38,4 V | 1920 Wh | 50 A, 60 A 30 min | ~9,6 kg (envío) | — | — | 399,99 EUR | 208 | [VERIFICADO: https://www.litime.de/products/36v-50ah-bluetooth-lithium-batterie-group31-marine-trolling-motor] |
| Biltema | — | — | — | — | — | — | Solo LiFePO4 de arranque 2–3,5 Ah (399–549 DKK): **no sirve** | [VERIFICADO: https://find.biltema.com/v4/web/typeahead/400/da/?query=LiFePO4&take=12] |

Caja de batería: Biltema Batteriboks 340×200×245 mm interior, plástico antiácido con soporte y correa, **105 DKK** (entra la Power Queen 24 V 26,0×16,8×21,0 cm) [VERIFICADO: https://www.biltema.dk/baad/marinebatterier-og-tilbehor/batteribokse/batteriboks-340-x-200-x-245-mm-2000048673]. No declara IP → la estanqueidad la da la batería (IP65) + ubicación elevada.

---

## 5. Cargador

| Producto | Salida | Conexión | IP | Precio | Fuente |
|---|---|---|---|---|---|
| **Power Queen 29,2 V 20 A** | 29,2 V / 20 A, 100–240 VAC, ~1,3 kg | **Anderson 50 A** + terminales M8 | buscar | **102,99 EUR** | [VERIFICADO: https://www.ipowerqueen.de/products/power-queen-29-2v-20a-lifepo4-ladegerat] |
| LiTime 29,2 V 20 A | 29,2 V / 20 A | cable 145 cm con extensión Anderson 25 cm | — | 132,99 EUR | [VERIFICADO: https://www.litime.de/products/litime-29-2v-20a-lithium-batterieladegerat-fur-24v-lifepo4-lithium-batterie] |
| LiTime 36 V 15 A (para 12S) | 43,8 V / 15 A | — | IP66 | 132,99 EUR | [VERIFICADO: https://www.litime.de/products/litime-36v-15a-wasserdichtes-lithium-batterieladegerat] |
| LiTime 14,6 V 10 A (para 12 V individual) | 14,6 V / 10 A | M8 + Anderson 50 A | — | 65,99 EUR | [VERIFICADO: https://www.litime.de/products/litime-12v-10a-lithium-batterie-ladegerat-fur-12v-lifepo4-lithium-batterie] |
| AliExpress 29,2 V 10 A | 29,2 V / 10 A | — | — | 31,09 EUR (272 vendidos) | [VERIFICADO: https://www.aliexpress.com/w/wholesale-lifepo4-charger-29.2v-10a.html] |
| Biltema 12/24 V 15 A | 15,9 V máx.; 7,5 A en 24 V; "Batteritype" = *"AGM, GEL, WET, SMT, MF, LiFePO4 (12 V)"* y sin LiFePO4 en la otra línea → **no apto 24 V LFP** [VERIFICADO: tabla de propiedades de la misma página] | pinzas | IP20 | 459 DKK | [VERIFICADO: https://www.biltema.dk/bil---mc/bilbatterier/batteriladere/batterilader-1224-v-15-a-2000045787] |

---
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

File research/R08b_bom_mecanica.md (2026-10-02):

# R08b — Sourcing de la BOM mecánica con envío a Dinamarca (cola larga eléctrica P1)

Consulta: 2026-10-01. Autor: subagente de investigación P1. Alcance: piezas mecánicas compradas (no motor/ESC/batería) para la arquitectura candidata "cola larga" (motor seco arriba + HTD-5M + eje 316 inclinado en tubo + hélice de fueraborda chico con pasador de corte + kick-up), con precio y link **abierto en esta sesión**.

**Método y límites.** El cupo de WebSearch de la sesión estaba agotado, y Bing/DDG/Brave/Mojeek devolvían bloqueos o basura. Por eso fui directo a los buscadores y API de cada tienda: Watski `/search/?query=`, Biltema `find.biltema.com/v4/web/typeahead/400/da/`, AWN `search/suggest.json` y `products/<handle>.js`, Kugellager-Shop `catalogsearch`, igus `product/35?artNr=`, 3DJake `ld+json`, Dold y Tohatsu.de en HTML. No pude abrir estas tiendas (403/502/TLS/Cloudflare): kugellager-express.de, svb.de, maedler.de, misumi-ec, accu.co.uk, ebay.de/.dk, amazon.de (captcha/503), simplybearings (429), wurth.dk, 3djake.dk (certificado autofirmado vía proxy), polymaker.com, kipp/norelem (SSL), boats.net y marineengine (403), solasprop.com, baadudstyr.dk, 12voltshop.dk y varias metalerías DE/DK.

**Convenciones.** Los precios van tal cual los muestra la tienda: DKK con 25 % de moms para Watski y Biltema; EUR con 19 % de MwSt alemán para AWN, Kugellager-Shop, Dold y 3DJake.de, salvo donde se aclara. Para un comprador privado en DK, una tienda de la UE debería facturar con IVA danés (25 %), así que el precio final ≈ neto × 1,25 [ESTIMADO: reglas OSS de venta a distancia UE, memoria técnica, no verificado]. Uso 1 EUR = 7,46 DKK [ESTIMADO: paridad ERM-II 7,46038, memoria técnica, no verificado].

---
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

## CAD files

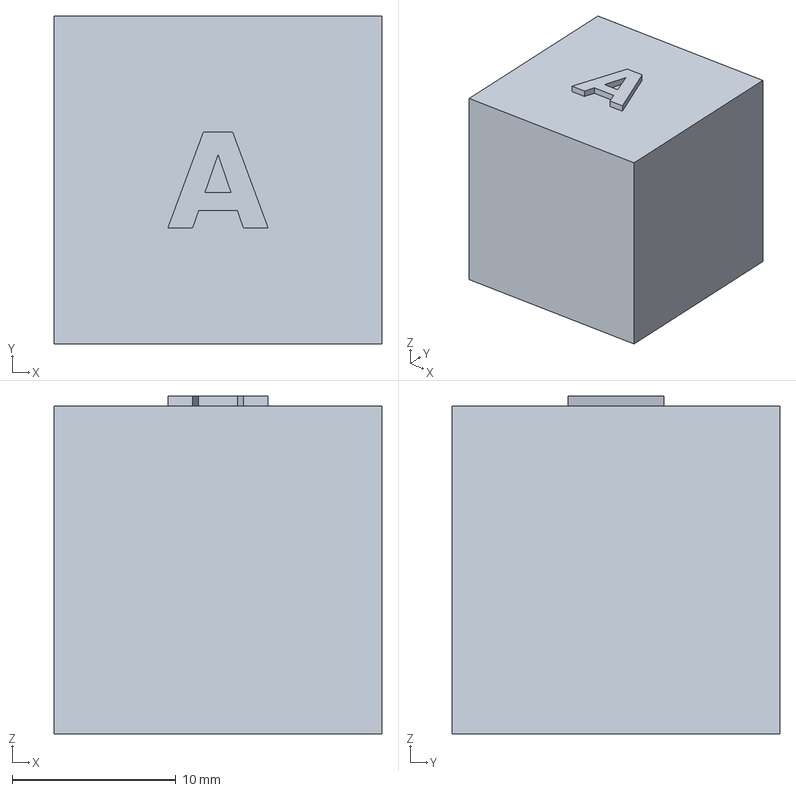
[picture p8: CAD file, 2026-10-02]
04_diseno/probetas/step/P1.7A_cubo_absorcion_A.step
20.0 x 20.0 x 20.6 mm

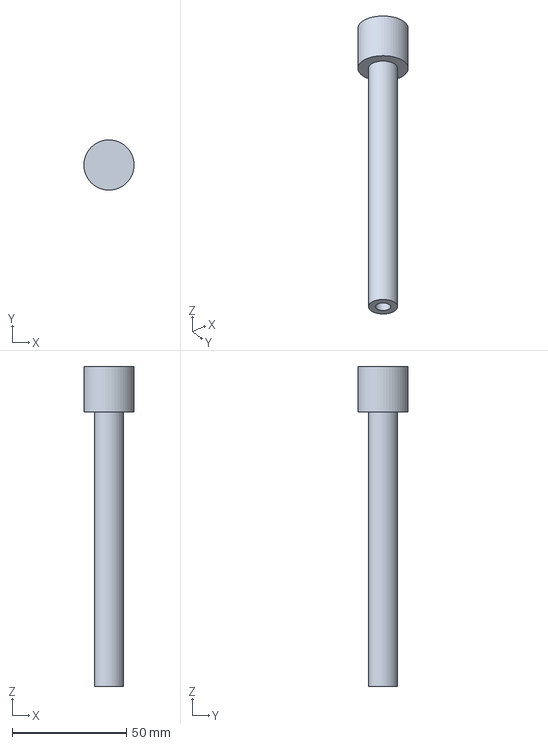
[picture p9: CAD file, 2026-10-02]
04_diseno/step/P1-REV-07_terminal_mach5.step
22.0 x 22.0 x 140.0 mm

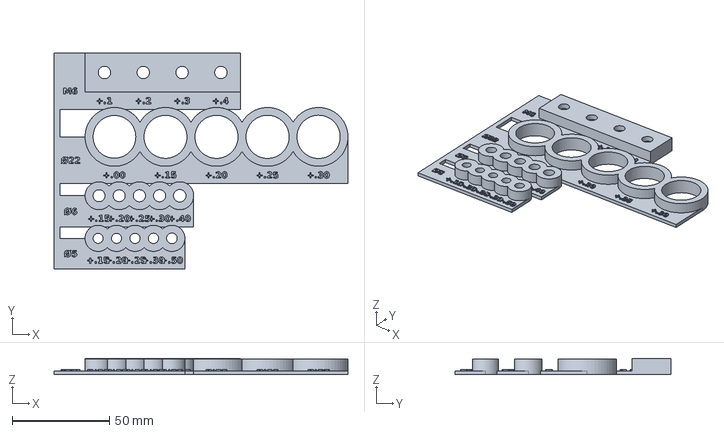
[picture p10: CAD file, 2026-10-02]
04_diseno/probetas/step/P1.1A_peine_agujeros.step
151.5 x 111.2 x 8.40 mm

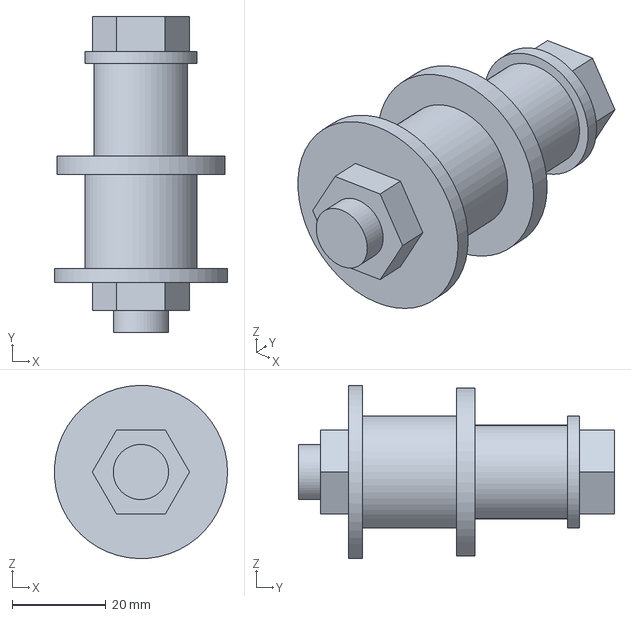
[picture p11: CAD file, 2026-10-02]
04_diseno/step/P1-REV-02_perno_bucket.step
37.0 x 67.5 x 37.0 mm

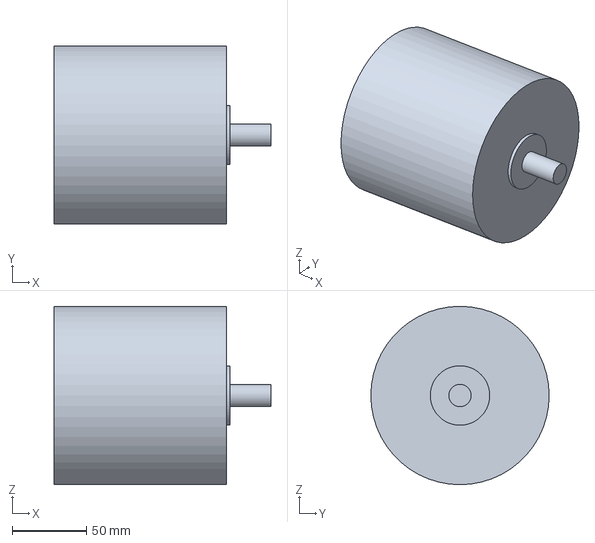
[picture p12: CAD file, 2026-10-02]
04_diseno/step/P1-MOT-01_motor.step
146.0 x 120.0 x 120.0 mm

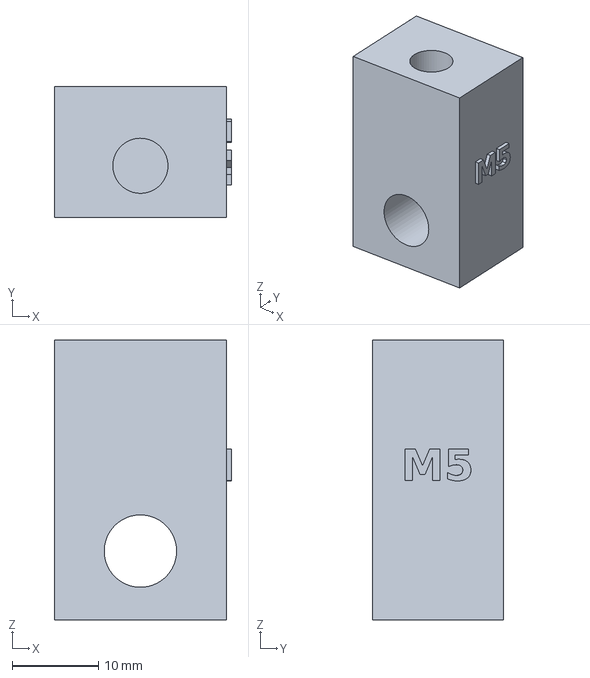
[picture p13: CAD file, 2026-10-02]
04_diseno/probetas/step/P1.4_inserto_M5.step
20.6 x 15.2 x 32.5 mm

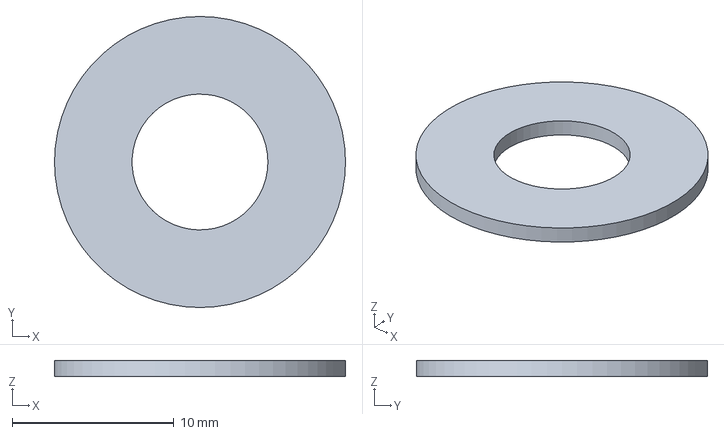
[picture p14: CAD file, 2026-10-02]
04_diseno/step/P1-STE-03_arandela_pom.step
18.0 x 18.0 x 1.00 mm

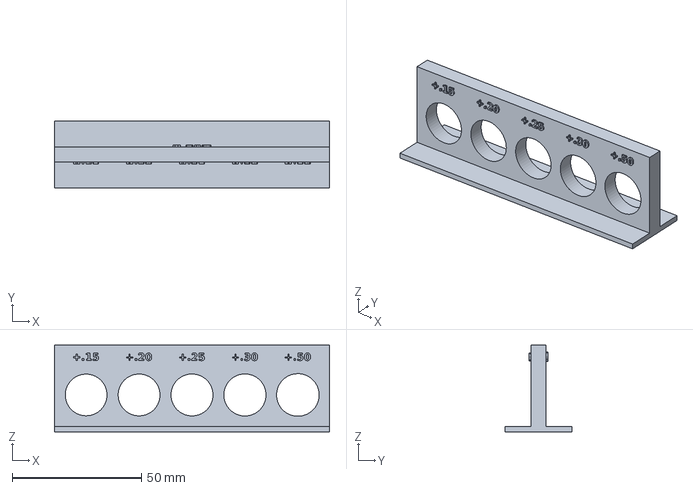
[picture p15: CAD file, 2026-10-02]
04_diseno/probetas/step/P1.1H_agujeros_horizontales.step
106.5 x 26.0 x 33.5 mm

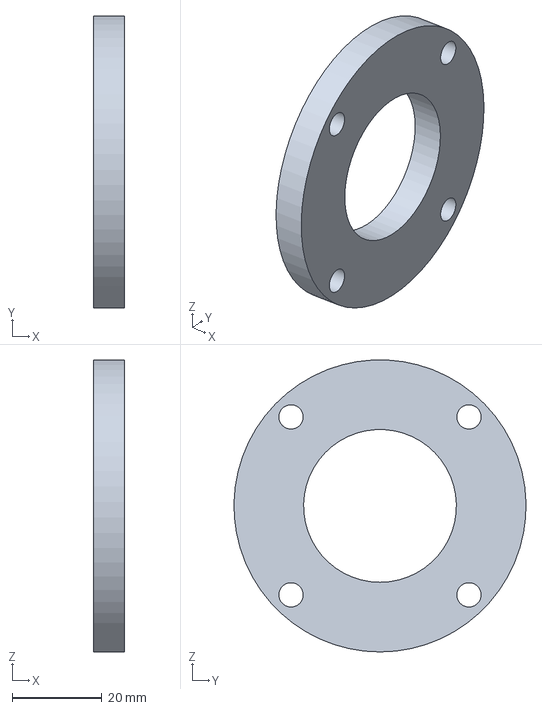
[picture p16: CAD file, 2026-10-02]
04_diseno/step/P1-DRV-06_bearing_cover.step
7.00 x 65.0 x 65.0 mm

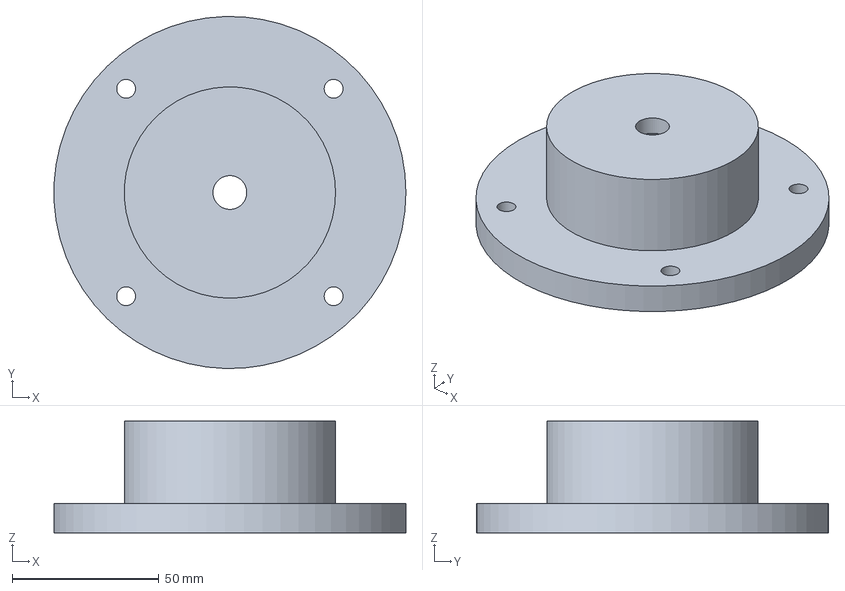
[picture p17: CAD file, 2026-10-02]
04_diseno/probetas/step/P1.6A_caja_brida.step
119.9 x 120.0 x 38.0 mm

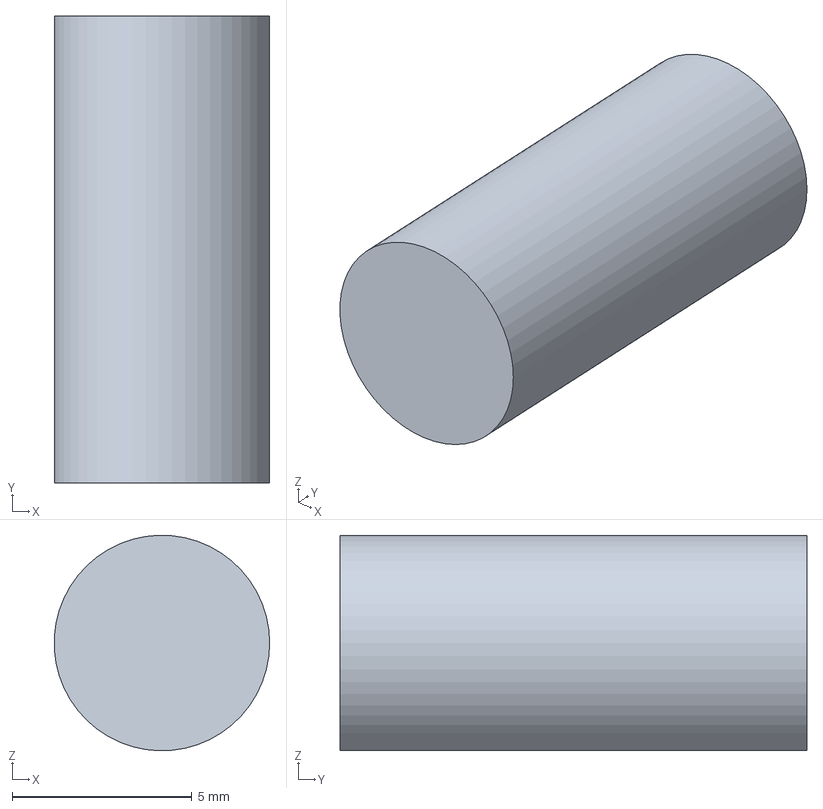
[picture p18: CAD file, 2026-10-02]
04_diseno/step/P1-CTL-12_perno_enclav.step
5.99 x 13.0 x 6.00 mm

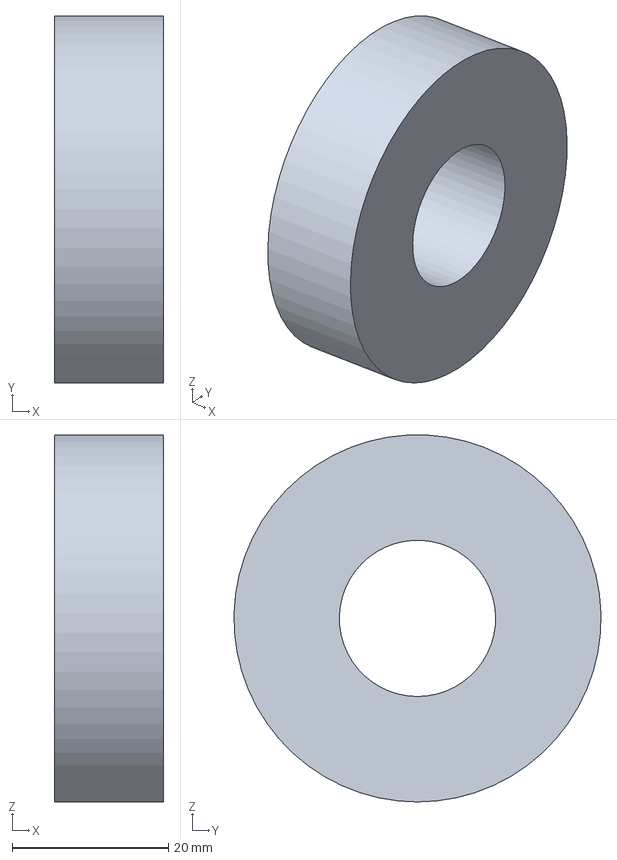
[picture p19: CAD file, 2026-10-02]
04_diseno/step/P1-DRV-04_bearing_7204BEP.step
14.0 x 47.0 x 47.0 mm

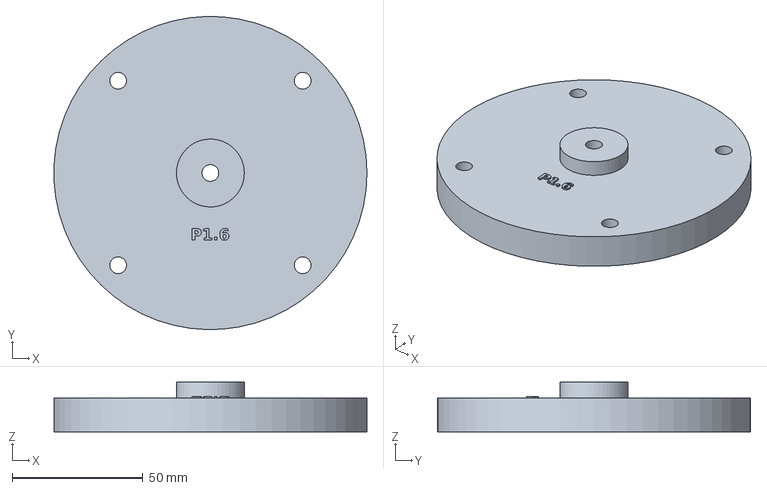
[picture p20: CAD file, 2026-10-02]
04_diseno/probetas/step/P1.6B_tapa_oring_purga.step
119.9 x 120.0 x 19.0 mm

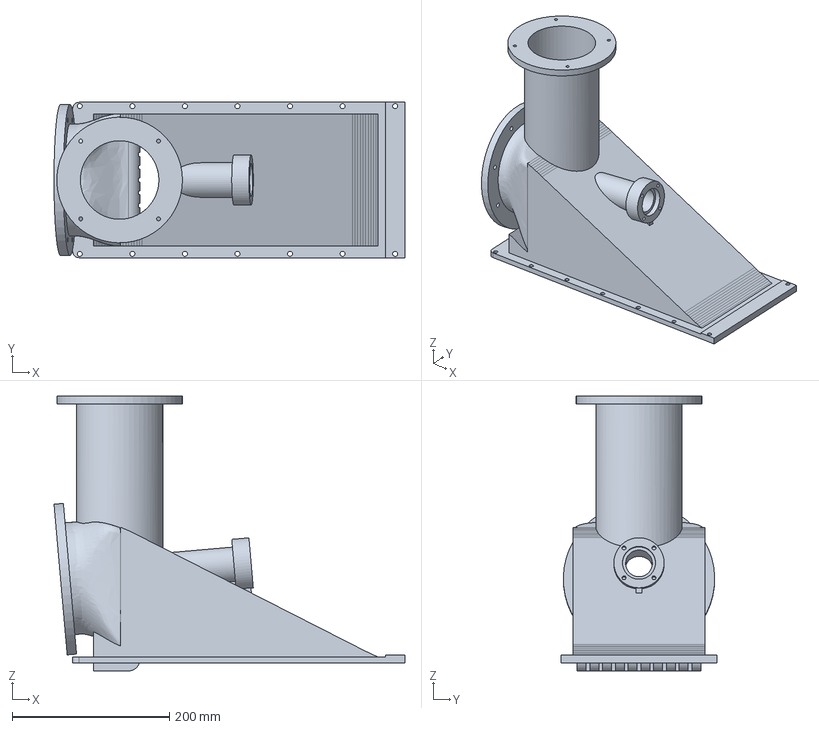
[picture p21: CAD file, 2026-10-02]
04_diseno/step/P1-INT-01_conducto.step
446.9 x 198.0 x 350.0 mm

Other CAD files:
04_diseno/probetas/step/P1.7B_cubo_absorcion_B.step
04_diseno/probetas/step/P1.7C_cubo_absorcion_C.step
04_diseno/step/P1-INT-04_tapa_inspeccion.step
04_diseno/step/P1-DRV-05_locknut_KM4.step
04_diseno/probetas/stl/P1.1A_peine_agujeros.stl
04_diseno/probetas/stl/P1.1H_agujeros_horizontales.stl
04_diseno/probetas/stl/P1.4_inserto_M5.stl
04_diseno/probetas/stl/P1.6A_caja_brida.stl
04_diseno/probetas/stl/P1.6B_tapa_oring_purga.stl
04_diseno/probetas/stl/P1.7A_cubo_absorcion_A.stl
04_diseno/probetas/stl/P1.7B_cubo_absorcion_B.stl
04_diseno/probetas/stl/P1.7C_cubo_absorcion_C.stl
04_diseno/step/P1-BAT-01_bateria.step
04_diseno/step/P1-CTL-01_placa_espejo.step
04_diseno/step/P1-CTL-02_caja_acel.step
04_diseno/step/P1-CTL-03_soporte_kill.step
04_diseno/step/P1-CTL-04_pasamuros_m66.step
04_diseno/step/P1-CTL-05_prensaestopas.step
04_diseno/step/P1-CTL-06_terminal_m66.step
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

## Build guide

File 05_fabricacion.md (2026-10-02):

# 05 — Fabricación del waterjet P1-J: qué se hace cómo, impresión, mecanizado, soldadura, CNC, anodizado y ensayos

**Estado:** verificado *en software* — rutas de fabricación cruzadas entre `resultados/manifest.json` y `bom.csv`, CAD de probetas cerrado y dentro de la envolvente (`build_probetas.py`), perfiles cargados y laminados con PrusaSlicer 2.7.2 CLI (`validar_perfiles.py` → `prusaslicer/slice_report.json`), criterios de ensayo leídos de `sizing.json` / `estructural.json`, `tests/test_probetas.py`. **Nada está impreso, torneado, soldado ni ensayado: todo lo físico es [NO EJECUTADO] — pendiente de taller.**

Las tablas entre `<!-- FAB:… -->` las genera `04_diseno/probetas/tabla_fabricacion.py` (lo llama `build_probetas.py`, paso 6e de `run_all.py`) desde `resultados/manifest.json`, `bom.csv`, `resultados/sizing.json`, `resultados/estructural.json`, `inputs.yaml`, `04_diseno/probetas/probetas_manifest.json`, `prusaslicer/slice_report.json` y el código de `04_diseno/piezas/`: **no editarlas a mano**. Los números sueltos del texto van con marcadores `<!--V:…-->` (los refresca `docgen.py`).

Fuentes: research/R05 (PETG, sellado, insertos), R06 §6 y R10b H21 (galvánica), R08b §6 (Tef-Gel, arandelas aislantes), R11 §6 (CNC 5 ejes y SLM 316L), R12 §3 (holgura de punta), §7.2 (presiones) y §7.6 (pasador de corte).

---

## 0. Resumen

- **El jet es casi todo metal.** De <!--V:manifest.totals.n_parts:-->65<!--/V--> tipos de pieza, solo cinco son impresas en PETG (tapa de inspección P1-INT-04, base y capota del controlador P1-ELE-01/02, caja de palancas P1-CTL-02, soporte del kill switch P1-CTL-03): <!--V:manifest.totals.printed_mass_g:.0f-->1051<!--/V--> g y <!--V:manifest.totals.printed_hours:.0f-->58<!--/V--> h según el manifest (PrusaSlicer da más: §2.6). El resto es Al 5083 cortado a láser y soldado (toma, bucket, placas), Al 6061/6082 y AISI 316L torneado, y **CNC 5 ejes** para impulsor (316L) y estator (6061-T6).
- **Servicios de fabricación** en la BOM: <!--V:bom.services_eur:.0f-->4015<!--/V--> € (CNC, torneado grande, láser, soldadura, anodizado); materia prima para el torno propio y el taller: <!--V:bom.raw_material_eur:.0f-->1326<!--/V--> €.
- **Torno propio** hasta el Ø que supone la BOM (`inputs.yaml bom.lathe_max_d_mm`, [SUPUESTO]: **medir**); carcasa y tobera fija lo superan y van a taller (§3).
- **Ensayos:** 4 probetas impresas (P1.1 holguras, P1.4 inserto M5, P1.6 tapa con O-ring y purga a la presión de cierre, P1.7 absorción) y 4 ensayos de taller sin CAD (P1.9 juego de semipasadores de corte, P1.10 bujes POM en agua, P1.11 hidrostática de la bomba, P1.12 holgura de punta), todos con criterio numérico tomado de los JSON (§7).
- **Hallazgos para el diseño:** §10.

---

## 1. Qué se fabrica cómo

Una fila por pieza del manifest; la ruta se deduce de los servicios `S-*` que la cubren en `bom.csv` (columna `cubre`) y de la materia prima `MP-*` que la nombra. Es un bloque **nuevo**, `FAB:procesos`, y no `AUTO:parts_list` de `docgen.py`: ese bloque solo trae el proceso del manifest, donde «torneada» agrupa torno, fresa, láser y soldadura.

<!-- FAB:procesos -->
| ID | Pieza | Material | Cant. | Proceso (manifest) | Ruta de fabricación | Servicio (bom.csv) | Materia prima (bom.csv) | g c/u (CAD) | Plano |
|---|---|---|---|---|---|---|---|---|---|
| P1-BAT-01 | bateria | referencia | 2 | comprada | Comprada (B-BAT) | — | — | 19 800 | — |
| P1-CTL-01 | placa_espejo | Al 5083 | 1 | torneada | corte láser/agua → taladrado/plegado propio | S-LASER | MP-5083-T6 | 489 | `P1-CTL-01_placa_espejo.svg` |
| P1-CTL-02 | caja_acel | PETG | 1 | impresa | Impresa PETG — perfil **cubiertas** (§2) | — | — | 134 | — |
| P1-CTL-03 | soporte_kill | PETG | 1 | impresa | Impresa PETG — perfil **estructural** (§2) | — | — | 120 | — |
| P1-CTL-04 | pasamuros_m66 | AISI 316 | 1 | torneada | torno propio | — | MP-316-D35 | 128 | `P1-CTL-04_pasamuros_m66.svg` |
| P1-CTL-05 | prensaestopas | referencia | 2 | comprada | Comprada (B-GLAND16, B-GLAND20) | — | — | 15 | — |
| P1-CTL-06 | terminal_m66 | Acero | 1 | comprada | Comprada (B-M66) | — | — | 350 | — |
| P1-CTL-07 | terminal_mach5_consola | Acero | 1 | comprada | Comprada (B-MACH5) | — | — | 120 | — |
| P1-CTL-08 | placa_central | Al 5083 | 1 | torneada | corte láser/agua → soldadura TIG (taller) | S-LASER, S-WELD-AL | MP-5083-T6 | 219 | `P1-CTL-08_placa_central.svg` |
| P1-CTL-09 | palanca_acel | Al 6061-T6 | 1 | torneada | corte láser/agua → taladrado/plegado propio | S-LASER | MP-6061-T8 | 102 | `P1-CTL-09_palanca_acel.svg` |
| P1-CTL-10 | palanca_bucket | Al 6061-T6 | 1 | torneada | corte láser/agua → soldadura TIG (taller) | S-LASER, S-WELD-AL | MP-6061-T8 | 137 | `P1-CTL-10_palanca_bucket.svg` |
| P1-CTL-11 | eje_palancas | AISI 316 | 1 | torneada | torno propio | — | MP-316-D20 | 39 | `P1-CTL-11_eje_palancas.svg` |
| P1-CTL-12 | perno_enclav | AISI 316 | 2 | torneada | torno propio | — | MP-316-D8 | 3 | `P1-CTL-12_perno_enclav.svg` |
| P1-CTL-13 | varilla_consola | AISI 316 | 1 | comprada | Comprada (B-ROD5) | — | — | 40 | — |
| P1-CTL-14 | gatillo | Al 6061-T6 | 1 | torneada | corte láser/agua → taladrado/plegado propio | S-LASER | MP-6061-T6 | 13 | `P1-CTL-14_gatillo.svg` |
| P1-CTL-20 | consola_ref | referencia | 1 | referencia | Referencia (no se fabrica: casco, consola, volante) | — | — | 0 | — |
| P1-CTL-21 | volante_ref | referencia | 1 | referencia | Referencia (no se fabrica: casco, consola, volante) | — | — | 0 | — |
| P1-DRV-01 | shaft | AISI 316 | 1 | torneada | torno propio | — | MP-316-D28 | 1 181 | `P1-DRV-01_shaft.svg` |
| P1-DRV-02 | seal_housing | AISI 316 | 1 | torneada | torno propio | — | MP-316-D75 | 311 | `P1-DRV-02_seal_housing.svg` |
| P1-DRV-03 | bearing_bracket | Al 5052/6082 | 1 | torneada | corte láser/agua → soldadura TIG (taller) | S-LASER, S-WELD-AL | MP-6082-T12 | 1 642 | `P1-DRV-03_bearing_bracket.svg` |
| P1-DRV-04 | bearing_7204BEP | Acero | 2 | comprada | Comprada (B-BRG) | — | — | 110 | — |
| P1-DRV-05 | locknut_KM4 | Acero | 1 | comprada | Comprada (B-KM4) | — | — | 25 | — |
| P1-DRV-06 | bearing_cover | Al 5052/6082 | 1 | torneada | torno propio | — | MP-6082-D70 | 44 | `P1-DRV-06_bearing_cover.svg` |
| P1-DRV-07 | mech_seal_MG1_20 | referencia | 1 | comprada | Comprada (B-SEAL) | — | — | 60 | — |
| P1-DRV-08 | coupling_rotex24 | referencia | 1 | comprada | Comprada (B-CPL) | — | — | 600 | — |
| P1-ELE-01 | esc_stand | PETG | 1 | impresa | Impresa PETG — perfil **cubiertas** (§2) | — | — | 263 | — |
| P1-ELE-02 | esc_hood | PETG | 1 | impresa | Impresa PETG — perfil **cubiertas** (§2) | — | — | 207 | — |
| P1-ELE-03 | cooling_outlet | AISI 316 | 1 | comprada | Comprada (B-COOL-THRU) | — | — | 45 | — |
| P1-ELE-04 | esc | referencia | 1 | comprada | Comprada (B-ESC) | — | — | 2 000 | — |
| P1-INT-01 | conducto | Al 5083 | 1 | torneada | corte láser/agua → soldadura TIG (taller) | S-LASER, S-WELD-INT | MP-5083-T5 | 4 699 | `P1-INT-01_conducto.svg` |
| P1-INT-02 | placa_base | Al 5083 | 1 | torneada | corte láser/agua → soldadura TIG (taller) | S-LASER, S-WELD-INT | MP-5083-T10 | 3 042 | `P1-INT-02_placa_base.svg` |
| P1-INT-03 | rejilla | AISI 316 | 1 | torneada | corte láser/agua → soldadura TIG (taller) | S-LASER, S-WELD-316 | MP-316-T4 | 2 014 | `P1-INT-03_rejilla.svg` |
| P1-INT-04 | tapa_inspeccion | PETG | 1 | impresa | Impresa PETG — perfil **sellado** (§2) | — | — | 327 | — |
| P1-MOT-01 | motor | referencia | 1 | comprada | Comprada (B-MOT) | — | — | 4 400 | — |
| P1-MOT-02 | motor_mount | Al 5052/6082 | 1 | torneada | corte láser/agua → soldadura TIG (taller) | S-LASER, S-WELD-AL | MP-6082-T10 | 842 | `P1-MOT-02_motor_mount.svg` |
| P1-PMP-01 | housing | Al 6061-T6 | 1 | torneada | torno de taller → anodizado duro | S-TURN-HSG, S-ANOD | MP-6061-TUBO-P1-PMP-01 | 1 492 | `P1-PMP-01_housing.svg` |
| P1-PMP-02 | wear_ring | AISI 316 | 1 | torneada | torno propio | — | MP-316-TUBO-P1-PMP-02 | 1 187 | `P1-PMP-02_wear_ring.svg` |
| P1-PMP-03 | impeller | AISI 316 | 1 | torneada | CNC 5 ejes (taller) | S-CNC-IMP | — | 1 335 | `P1-PMP-03_impeller_hub.svg`, `P1-PMP-03_tabla_angulos_alabes.svg` |
| P1-PMP-04 | pin_band | AISI 316 | 1 | torneada | torno propio | — | MP-316-D70 | 76 | `P1-PMP-04_pin_band.svg` |
| P1-PMP-05 | shear_pin | Al 6061-T6 | 2 | torneada | torno propio | — | MP-6061-D4 | 1 | `P1-PMP-05_shear_pin.svg` |
| P1-PMP-06 | stator | Al 6061-T6 | 1 | torneada | CNC 5 ejes (taller) → anodizado duro | S-CNC-STAT, S-ANOD | — | 1 524 | `P1-PMP-06_stator.svg` |
| P1-PMP-07 | water_bushing | POM-C | 1 | torneada | torno propio | — | MP-POM-D30 | 12 | `P1-PMP-07_water_bushing.svg` |
| P1-PMP-08 | fixed_nozzle | Al 6061-T6 | 1 | torneada | torno de taller → anodizado duro | S-TURN-NOZ, S-ANOD | MP-6061-TUBO-P1-PMP-08 | 1 408 | `P1-PMP-08_fixed_nozzle.svg` |
| P1-PMP-09 | transom_plate | Al 5083 | 1 | torneada | torno de taller | S-TURN-TP | MP-5083-BLQ-P1-PMP-09 | 449 | `P1-PMP-09_transom_plate.svg` |
| P1-PMP-10 | transom_gasket | NBR | 1 | comprada | Comprada (B-GASKET) | — | — | 35 | — |
| P1-PMP-11 | pivot_bushing | POM-C | 2 | torneada | torno propio | — | MP-POM-D14 | 2 | `P1-PMP-11_pivot_bushing.svg` |
| P1-REF-01 | casco | referencia | 1 | referencia | Referencia (no se fabrica: casco, consola, volante) | — | — | 0 | — |
| P1-REV-01 | bucket | Al 5083 | 1 | torneada | corte láser/agua → soldadura TIG (taller) | S-LASER, S-WELD-AL | MP-5083-AROS, MP-5083-T8 | 1 241 | `P1-REV-01_bucket_brazo_babor.svg`, `P1-REV-01_bucket_brazo_estribor.svg`, `P1-REV-01_bucket_cuchara.svg` |
| P1-REV-02 | perno_bucket | Dúplex 1.4462 | 2 | torneada | torno propio | — | MP-DPX-D22, MP-DPX-D40 | 218 | `P1-REV-02_casquillo_pivote_bucket.svg`, `P1-REV-02_munon_pivote_bucket.svg` |
| P1-REV-03 | buje_bucket | POM-C | 2 | torneada | torno propio | — | MP-POM-D32 | 4 | `P1-REV-03_buje_bucket.svg` |
| P1-REV-04 | embolo | AISI 316 | 2 | torneada | torno propio | — | MP-316-D18, MP-316-D35 | 264 | `P1-REV-04_embolo_cuerpo.svg`, `P1-REV-04_embolo_perno.svg` |
| P1-REV-05 | soporte_mach5 | Al 5083 | 1 | torneada | corte láser/agua → soldadura TIG (taller) | S-LASER, S-WELD-AL | MP-5083-T6 | 190 | `P1-REV-05_soporte_mach5.svg` |
| P1-REV-06 | perno_varilla | AISI 316 | 1 | torneada | torno propio | — | MP-316-D16 | 10 | `P1-REV-06_perno_varilla.svg` |
| P1-REV-07 | terminal_mach5 | Acero | 1 | comprada | Comprada (B-MACH5) | — | — | 120 | — |
| P1-REV-08 | varilla_mach5 | AISI 316 | 1 | comprada | Comprada (B-ROD5) | — | — | 40 | — |
| P1-REV-09 | soporte_bowden | Al 5083 | 1 | torneada | corte láser/agua → soldadura TIG (taller) | S-LASER, S-WELD-AL | MP-5083-T6 | 96 | `P1-REV-09_balancin.svg`, `P1-REV-09_eje_balancin.svg`, `P1-REV-09_eslabon.svg`, `P1-REV-09_perno_manivela.svg`, `P1-REV-09_soporte_bowden.svg` |
| P1-REV-10 | bowden_embolo | AISI 316 | 2 | comprada | Comprada (B-BOWDEN) | — | — | 60 | `P1-REV-10_recorrido_vaina.svg` |
| P1-STE-01 | boquilla | Al 6061-T6 | 1 | torneada | torno + fresado 4 ejes (taller) → anodizado duro | S-MILL-STE, S-ANOD | MP-6061-BLQ-P1-STE-01 | 1 165 | `P1-STE-01_boquilla.svg` |
| P1-STE-02 | perno_sup | AISI 316 | 1 | torneada | torno propio | — | MP-316-D16 | 20 | `P1-STE-02_perno_sup.svg` |
| P1-STE-03 | arandela_pom | POM-C | 3 | torneada | torno propio | — | MP-POM-D20 | 0 | `P1-STE-03_arandela_pom.svg` |
| P1-STE-04 | brida_yugo | Al 5083 | 1 | torneada | corte láser/agua → taladrado/plegado propio | S-LASER | MP-5083-T20 | 173 | `P1-STE-04_brida_yugo.svg` |
| P1-STE-05 | perno_inf | AISI 316 | 1 | torneada | torno propio | — | MP-316-D10 | 11 | `P1-STE-05_perno_inf.svg` |
| P1-STE-06 | poste | Al 6061-T6 | 1 | torneada | torno propio → anodizado duro | S-ANOD | MP-6061-D50 | 151 | `P1-STE-06_poste.svg` |
| P1-STE-07 | brazo | Al 5083 | 1 | torneada | corte láser/agua → taladrado/plegado propio | S-LASER | MP-5083-T10 | 34 | `P1-STE-07_brazo.svg` |
| P1-STE-08 | tope_direccion | Al 5083 | 1 | torneada | corte láser/agua → taladrado/plegado propio | S-LASER | MP-5083-BLQ-P1-STE-08 | 82 | `P1-STE-08_tope_direccion.svg` |

Piezas por proceso del manifest: comprada **16**, impresa **5**, referencia **3**, torneada **41** (65 tipos). «torneada» en el manifest = toda pieza mecanizada (torno, fresa, láser, soldada).
<!-- /FAB:procesos -->

---

## 2. Impresión 3D (PETG)

### 2.1 Material, secado y almacenamiento

| Paso | Valor | Etiqueta |
|---|---|---|
| Compra | PETG 1,75 mm con **HDT(1,8 MPa) ≥ 70 °C declarada** (PolyLite 75 °C; Prusament y Bambu 68 °C no llegan) | [VERIFICADO: research/R05 A1, S1–S3; inputs.yaml materials.PETG.hdt_min_purchase_c] |
| Temperatura de servicio | ≤ 50 °C en la pieza: controlador y consola al sol, lejos del motor | [ESTIMADO: inputs.yaml materials.PETG.t_service_max_c] |
| Color | Blanco, gris claro o natural (consola al sol) | [ESTIMADO: research/R05 A4] |
| Secado | **65 °C × 6–8 h**; 8 h si la bobina estuvo abierta | [VERIFICADO: S2 "65°C/6H"; S3 "Blast Drying Oven: 65 °C, 8 h"] |
| Almacenamiento | Caja estanca con desecante, **HR < 20 %**; la tapa P1-INT-04 (la impresión más larga) se imprime **desde la caja seca** | [VERIFICADO: S3] |
| Piezas impresas | **No** recocer ni secar a 60–70 °C: deforman | [VERIFICADO: S3] |

### 2.2 Perfiles PrusaSlicer (`prusaslicer/`)

Tres familias sobre impresora y filamento comunes (`P1_impresora_Ender3S1.ini`, `P1_filamento_PETG.ini`); la familia de cada pieza está en `04_diseno/probetas/familias.py` y cada probeta se imprime con la de la pieza que representa. Uso CLI: `prusa-slicer --load P1_impresora_Ender3S1.ini --load P1_filamento_PETG.ini --load P1_impresion_sellado_0.15.ini --export-gcode pieza.stl`; en la GUI, importar `completo/P1_<familia>_completo.ini` (guardado por el propio PrusaSlicer). El perfil «fusible» del diseño anterior (patín) se eliminó: ninguna pieza impresa del jet es fusible (el fusible de par es el pasador de Al, P1.9).

<!-- FAB:perfiles -->
| Parámetro (print) | estructural (`P1_impresion_estructural_0.20.ini`) | sellado (`P1_impresion_sellado_0.15.ini`) | cubiertas (`P1_impresion_cubiertas_0.20.ini`) |
|---|---|---|---|
| **piezas** | P1-CTL-03 | P1-INT-04 | P1-CTL-02, P1-ELE-01, P1-ELE-02 |
| capa [mm] | 0.2 | 0.15 | 0.2 |
| 1.ª capa [mm] | 0.2 | 0.2 | 0.2 |
| perímetros | 6 | 5 | 5 |
| generador de perímetros | arachne | arachne | arachne |
| capas sólidas arriba | 6 | 8 | 5 |
| capas sólidas abajo | 5 | 7 | 4 |
| relleno base | 85% | 100% | 30% |
| patrón | gyroid | rectilinear | gyroid |
| ángulo de relleno [°] | 45 | 45 | 45 |
| solape relleno–perímetro | 25% | 30% | 25% |
| costura | aligned | rear | aligned |
| costuras internas escalonadas | 1 | 1 | 0 |
| planchado | 0 | 1 | 0 |
| v perímetro externo [mm/s] | 25 | 20 | 30 |
| v perímetros [mm/s] | 40 | 30 | 45 |
| v relleno [mm/s] | 60 | 45 | 70 |
| v relleno sólido [mm/s] | 40 | 35 | 50 |
| soportes (por defecto) | 0 | 0 | 0 |
| compensación pata de elefante [mm] | 0.2 | 0.2 | 0.2 |

| Archivo | Clave | Valor |
|---|---|---|
| `P1_filamento_PETG.ini` | first_layer_temperature | 245 |
| `P1_filamento_PETG.ini` | temperature | 245 |
| `P1_filamento_PETG.ini` | first_layer_bed_temperature | 80 |
| `P1_filamento_PETG.ini` | bed_temperature | 75 |
| `P1_filamento_PETG.ini` | min_fan_speed | 15 |
| `P1_filamento_PETG.ini` | max_fan_speed | 35 |
| `P1_filamento_PETG.ini` | bridge_fan_speed | 60 |
| `P1_filamento_PETG.ini` | disable_fan_first_layers | 3 |
| `P1_filamento_PETG.ini` | filament_max_volumetric_speed | 8 |
| `P1_filamento_PETG.ini` | filament_retract_length | 1 |
| `P1_filamento_PETG.ini` | filament_retract_speed | 30 |
| `P1_impresora_Ender3S1.ini` | bed_shape | 5x5,215x5,215x215,5x215 |
| `P1_impresora_Ender3S1.ini` | max_print_height | 260 |
| `P1_impresora_Ender3S1.ini` | nozzle_diameter | 0.4 |
| `P1_impresora_Ender3S1.ini` | gcode_flavor | marlin2 |
| `P1_impresora_Ender3S1.ini` | machine_max_acceleration_extruding | 1000 |
<!-- /FAB:perfiles -->

**Por qué.**
- **sellado** (P1-INT-04): es la única pieza impresa **mojada y a presión** (presión de cierre de la bomba <!--V:sizing.loads.p_pump_max_Pa:.0f-->67234<!--/V--> Pa como succión o contrapresión; recuperación a 30 km/h <!--V:est.loads.structural_toma.p_ram_Pa:.0f-->24622<!--/V--> Pa). El PETG pierde agua "through the seams and contact points between perimeters and solid infill" [VERIFICADO: research/R05 S22] → 100 % de relleno con 30 % de solape, 5 perímetros, capa 0,15 (Sa 10–13 µm contra 20–24 µm a 0,21 mm [VERIFICADO: S18]). La **cara del O-ring va sobre la cama** (la más lisa y plana); planchado solo en la cara de arriba (apoyo de arandelas y de la arandela de estanqueidad de la purga).
- **cubiertas** (P1-ELE-01/02, P1-CTL-02): piezas **secas** y fuera de la ruta de carga de mando; 5 perímetros y 30 % gyroid, como pide la orientación del manifest para CTL-02. Con 0,45 mm de ancho de extrusión, 5 perímetros son 2,25 mm por lado y 4,5 mm entre las dos caras [CALCULADO]: una pared de hasta 4,5 mm queda maciza, pero las paredes de **5 mm de P1-CTL-02** (auditoría ronda 3, FEA: σZ entre capas) dejan en el medio una franja de ≈ 0,5 mm [CALCULADO] que llena el relleno de huecos (*gap fill*) de PrusaSlicer. Verificar en la vista previa del laminado que esa franja no quede vacía; si queda, usar 6 perímetros en la caja. FS mínimos de `estructural.json` en la tabla §2.3.
- **estructural** (P1-CTL-03 y peines P1.1): el soporte del kill switch es un **elemento de seguridad** (el tirón del cordón tiene que sacar el clip, no romper el soporte, y el golpe a la seta cruza capas): 6 perímetros, 85 % gyroid, velocidades moderadas.
- **Filamento y máquina:** boquilla 245 °C (techo 260 °C), cama 80/75 °C (techo 100 °C), cama PC con pegamento en barra, ventilador 15–35 %, retracción 1 mm [VERIFICADO: research/R05, S1–S3; ver comentarios de los `.ini`].

**Validación ejecutada** (`python prusaslicer/validar_perfiles.py`, PrusaSlicer 2.7.2 instalado): formato «clave = valor» sin duplicados; todas las claves existen en 2.7.2; límites de `inputs.yaml` (boquilla, cama, zona útil); PrusaSlicer carga y guarda las 3 familias; lamina las 8 probetas impresas y las 5 piezas del jet y el G-code repite temperatura, cama, perímetros, relleno, capa, costura, forma de cama y alto máximo. `slice_report.json` solo contiene piezas del waterjet.

### 2.3 Orientación por pieza

La orientación es la del CAD (`print_rot` de cada `META`; `build_all.py` exporta los STL ya orientados). El FS mínimo sale de `estructural.json`; soporte y avisos, del laminado real.

<!-- FAB:orientacion -->
| ID | Pieza | Cant. | Perfil, relleno | Por qué ese perfil (familias.py) | Orientación de impresión (manifest) | Envolvente [mm] | FS mín. (estructural.json) | Soporte auto / avisos PrusaSlicer | g c/u (CAD × solid_frac) | g c/u (PrusaSlicer) | h c/u (18 g/h) | h c/u (PrusaSlicer) |
|---|---|---|---|---|---|---|---|---|---|---|---|---|
| P1-CTL-02 | caja_acel | 1 | **cubiertas** 30 % | tapa de la unidad de palancas: sin cargas de mando (van a P1-CTL-08); 5 perímetros, 30 % (orientación del manifest) | Tapa sobre la cama (ranuras planas, sin soportes); ala arriba. 0,2 mm, 5 perímetros, 30 % giroide `print_rot=(180, 0, 0)` | 184×82×68 | 3,84 (Tapa PETG 6 mm: mano apoyada 150 N [SUPUESTO] (corta)) | sí · Floating bridge anchors, Long bridging extrusions | 134 | 162 | 7,4 | 11,8 |
| P1-CTL-03 | soporte_kill | 1 | **estructural** 85 % | en la ruta de carga de un elemento de seguridad (tirón del cordón, golpe a la seta); FS en structural.py | Base sobre la cama; la cara inclinada a 45° no necesita soportes. 0,2 mm, 5 perímetros `print_rot=(0, 0, 0)` | 100×130×55 | 4,21 (Cara PETG 10 mm: golpe sobre la seta 200 N [SUPUESTO] (cor…) | sí · Collapsing overhang | 120 | 186 | 6,7 | 18,2 |
| P1-ELE-01 | esc_stand | 1 | **cubiertas** 30 % | seca, sobre el piso; FS ≥ 16 (estructural.json); insertos M5 en nervios macizos — P1.4 | Base abierta sobre la cama; tablero arriba (puentes de 3,2 mm entre nervios, sin soportes). `print_rot=(0, 0, 0)` | 208×138×60 | 16,02 (Insertos M5 de la capota: apriete de las tiras de EPDM (so…) | sí · Floating bridge anchors, Long bridging extrusions | 263 | 364 | 14,6 | 29,1 |
| P1-ELE-02 | esc_hood | 1 | **cubiertas** 30 % | capota antisalpicaduras, seca; FS ≥ 6 (estructural.json) | Techo sobre la cama, paredes y nervios hacia arriba (sin soportes). `print_rot=(180, 0, 0)` | 208×126×55 | 6,39 (Techo de la capota: reacción de las tiras de EPDM (sosteni…) | no | 207 | 216 | 11,5 | 18,0 |
| P1-INT-04 | tapa_inspeccion | 1 | **sellado** 100 % | mojada y a presión: O-ring de cara y purga; sección llena, sin canales entre cordones (research/R05 B4) — P1.6/P1.7 | Cara de la ranura del O-ring y del hexágono de la tuerca sobre la cama (fondos lisos), resalte arriba, 100 % relleno `print_rot=(0, 0, 0)` | 160×160×19 | 3,34 (Tapa: ciclo marcha ↔ punto fijo Δp = 42 kPa (olas/maniobras)) | sí · Long bridging extrusions | 327 | 327 | 18,2 | 33,6 |
<!-- /FAB:orientacion -->

- **Soportes:** imprimir **sin soportes**; los avisos son puentes cortos. P1-INT-04: el techo del hexágono de la tuerca de purga y el de la ranura del O-ring son puentes; revisar en la vista previa que el del hexágono quede plano (si cuelga, la tuerca no asienta → repasar con lima). P1-CTL-03: "Collapsing overhang" en los rebajes de los pulsadores por dentro de la cara inclinada: el panel apoya en la cara exterior, no importa. P1-ELE-01: puentes del tablero entre nervios (previstos en el CAD).
- **Borde (brim):** solo si alto/huella > 2 (`familias.brim`); hoy solo la probeta P1.4.

### 2.4 Tuercas cautivas e insertos (inox en zona húmeda)

<!-- FAB:roscas -->
| Pieza | Tipo | Rosca | Comentario en el CAD |
|---|---|---|---|
| P1-ELE-01 | inserto térmico M5 (agujero Ø 6,4 × 10,5 mm) | M5 | nervios exteriores para la capota (insertos M5 arriba) |
| P1-INT-04 | tuerca cautiva, bolsillo hexagonal | M6 A4 (ISO 4032: 10 e/c) | purga: resalte arriba, hexágono de tuerca M6 desde abajo, agujero Ø6,4 |
<!-- /FAB:roscas -->

- **Zona húmeda (P1-INT-04): solo inox.** La purga usa una **tuerca ISO 4032 M6 A4 cautiva** en hexágono abierto a la cara interior (la presión la aprieta contra su asiento) y tornillo M6 × 12 A4 con arandela de estanqueidad; nada de latón: descincificación en agua con Zn > ~15 % [VERIFICADO: research/R05 A10.2, S30]. Si en el futuro se agrega un inserto en una pieza mojada: **inserto de inox 300** [VERIFICADO: existen, R05 S29], soldador a ~250–260 °C [ESTIMADO: R05 A10.3].
- **Zona seca (P1-ELE-01):** 4 insertos M5 para la capota (`B-INS` de la BOM) — se valida el proceso con **P1.4** antes de tocar la pieza. Agujero 1 mm más profundo que el inserto (el CAD lo trae), hundir el 90 % con la punta y el resto con herramienta plana fría [VERIFICADO: R05 S28]; a ras ±0,2 mm, perpendicular, sin fisura (lupa 10×) [SUPUESTO].
- **Torques de partida sobre PETG:** M4 1,0 · M5 2,0 N·m [ESTIMADO: research/R05 A10.3]; los M6 de la tapa de inspección van **a mano con perillas** y arandela ancha (aplastamiento verificado en `estructural.json`).
- **Fijación de roscas:** nada de Loctite 243 ni anaeróbicos sobre PETG (agrietamiento por tensión [VERIFICADO: R05 S31]); Loctite 425 o tuerca nyloc A4 [VERIFICADO: S32].

### 2.5 Post-proceso y cara de sello de P1-INT-04

- Sacar de la cama **fría**; repasar pata de elefante (compensada 0,2 mm en el perfil; afecta el ancho de la ranura del O-ring en la 1.ª capa: medir con calibre).
- **Planitud de la cara de sello ≤ 0,10 mm** con regla y galgas (±0,15 mm de profundidad ya lleva la compresión a 21–29 % [CALCULADO: research/R05 B3]); si no cumple, lapear sobre vidrio con lija al agua P240 → P600 en "ochos" y corregir el **fondo** de la ranura, no la cara. Ranura **2,57–2,72 × 4,50–4,75 mm** para cordón 3,53 [VERIFICADO: R05 B3]. La contracara es la brida de Al de la chimenea (P1-INT-01): refrentada en el taller de soldadura (§4).
- **O-ring:** cordón NBR70 Ø3,53 con empalme a tope (cianoacrilato) y **grasa de silicona**; nunca grasa mineral [VERIFICADO: R05 S24].
- **Química:** limpieza IPA:agua 50:50; acetona, MEK, THF prohibidos (disuelven PETG) [VERIFICADO: R05 S34]; epoxi solo en piezas frías (West 105/205 HDT 48 °C [VERIFICADO: S21]).
- **Inspección:** antes de cada salida, tapa P1-INT-04 (fisura o blanqueo en el resalte de la purga = cambiarla) y soporte del kill switch P1-CTL-03.

### 2.6 Tiempos y gramos

<!-- FAB:totales -->
| Conjunto | Impresiones | g (CAD × solid_frac) | g (PrusaSlicer) | h (18 g/h, inputs.yaml) | h (PrusaSlicer) |
|---|---|---|---|---|---|
| Piezas del jet (5 tipos) | 5 | 1 051 | 1 255 | 58 | 111 |
| Probetas impresas (P1.1, P1.4, P1.6, P1.7) | 10 | 526 | 537 | 29 | 57 |
| **Total** |  | **1 577** | **1 792** | **88** | **168** |

Bobinas de 1 kg: **3** [CALCULADO: máx(g) × (1 + 0,30) de purga, fallas y reimpresiones (inputs.yaml bom.filament.margin_frac, = bom.py)]. Laminado: PrusaSlicer-2.7.2+UNKNOWN based on Slic3r (with GUI support), perfiles y ajustes por objeto de esta página, sin soportes. Ritmo real de las piezas: **11,3 g/h** contra 18 g/h de inputs.yaml (printer.print_rate_g_h); la masa real de PrusaSlicer es 23 % mayor que la del manifest (CAD × solid_frac): 5–6 perímetros llenan casi todas las paredes de 3–6 mm.
<!-- /FAB:totales -->

---

## 3. Mecanizado: torno propio vs. taller

La BOM supone que todo lo de revolución con barra de Ø ≤ `bom.lathe_max_d_mm` sale del **torno manual del usuario** y que lo mayor (y lo de 4–5 ejes) va a un servicio `S-*`. **Ese límite es un [SUPUESTO] de la BOM: medir el volteo real** (sobre la bancada y sobre el carro transversal) y la **distancia entre puntos**, y corregir `inputs.yaml` antes de pedir material.

<!-- FAB:torno -->
| ID | Pieza | Material | Cant. | Pieza Ø × largo [mm] | Barra (bom.csv) | Barra Ø × largo [mm] | Ø barra ≤ 180 mm | Quién | Plano |
|---|---|---|---|---|---|---|---|---|---|
| P1-CTL-04 | pasamuros_m66 | AISI 316 | 1 | 43×32×32 | MP-316-D35 | Ø35 × 58 | sí | **torno propio** | `P1-CTL-04_pasamuros_m66.svg` |
| P1-CTL-11 | eje_palancas | AISI 316 | 1 | 18×38×18 | MP-316-D20 | Ø20 × 53 | sí | **torno propio** | `P1-CTL-11_eje_palancas.svg` |
| P1-CTL-12 | perno_enclav | AISI 316 | 2 | 6×13×6 | MP-316-D8 | Ø8 × 28 | sí | **torno propio** | `P1-CTL-12_perno_enclav.svg` |
| P1-DRV-01 | shaft | AISI 316 | 1 | 470×26×26 | MP-316-D28 | Ø28 × 485 | sí | **torno propio** | `P1-DRV-01_shaft.svg` |
| P1-DRV-02 | seal_housing | AISI 316 | 1 | Ø70,0 × 43,5 | MP-316-D75 | Ø75 × 58 | sí | **torno propio** | `P1-DRV-02_seal_housing.svg` |
| P1-DRV-06 | bearing_cover | Al 5052/6082 | 1 | Ø65,0 × 7,0 | MP-6082-D70 | Ø70 × 22 | sí | **torno propio** | `P1-DRV-06_bearing_cover.svg` |
| P1-PMP-02 | wear_ring | AISI 316 | 1 | Ø142,8 × 68,6 | MP-316-TUBO-P1-PMP-02 | Ø150 × 84 | sí | **torno propio** | `P1-PMP-02_wear_ring.svg` |
| P1-PMP-04 | pin_band | AISI 316 | 1 | Ø66,0 × 16,0 | MP-316-D70 | Ø70 × 31 | sí | **torno propio** | `P1-PMP-04_pin_band.svg` |
| P1-PMP-05 | shear_pin | Al 6061-T6 | 2 | 4×30×4 | MP-6061-D4 | Ø4 × 44 | sí | **torno propio** | `P1-PMP-05_shear_pin.svg` |
| P1-PMP-07 | water_bushing | POM-C | 1 | 30×28×28 | MP-POM-D30 | Ø30 × 45 | sí | **torno propio** | `P1-PMP-07_water_bushing.svg` |
| P1-PMP-11 | pivot_bushing | POM-C | 2 | 12×12×26 | MP-POM-D14 | Ø14 × 41 | sí | **torno propio** | `P1-PMP-11_pivot_bushing.svg` |
| P1-REV-02 | perno_bucket | Dúplex 1.4462 | 2 | 37×68×37 | MP-DPX-D40 | Ø40 × 39 | sí | **torno propio** | `P1-REV-02_casquillo_pivote_bucket.svg`, `P1-REV-02_munon_pivote_bucket.svg` |
| P1-REV-03 | buje_bucket | POM-C | 2 | Ø30,0 × 19,0 | MP-POM-D32 | Ø32 × 34 | sí | **torno propio** | `P1-REV-03_buje_bucket.svg` |
| P1-REV-04 | embolo | AISI 316 | 2 | 33×76×33 | MP-316-D35 | Ø35 × 90 | sí | **torno propio** | `P1-REV-04_embolo_cuerpo.svg`, `P1-REV-04_embolo_perno.svg` |
| P1-REV-06 | perno_varilla | AISI 316 | 1 | 13×26×13 | MP-316-D16 | Ø16 × 40 | sí | **torno propio** | `P1-REV-06_perno_varilla.svg` |
| P1-STE-02 | perno_sup | AISI 316 | 1 | 14×14×49 | MP-316-D16 | Ø16 × 64 | sí | **torno propio** | `P1-STE-02_perno_sup.svg` |
| P1-STE-03 | arandela_pom | POM-C | 3 | Ø18,0 × 1,0 | MP-POM-D20 | Ø20 × 16 | sí | **torno propio** | `P1-STE-03_arandela_pom.svg` |
| P1-STE-05 | perno_inf | AISI 316 | 1 | 8×8×33 | MP-316-D10 | Ø10 × 48 | sí | **torno propio** | `P1-STE-05_perno_inf.svg` |
| P1-STE-06 | poste | Al 6061-T6 | 1 | 44×44×140 | MP-6061-D50 | Ø50 × 155 | sí | **torno propio** | `P1-STE-06_poste.svg` |
| P1-PMP-01 | housing | Al 6061-T6 | 1 | Ø192,8 × 165,8 | MP-6061-TUBO-P1-PMP-01 | Ø200 × 181 | **NO** | taller (S-TURN-HSG) | `P1-PMP-01_housing.svg` |
| P1-PMP-08 | fixed_nozzle | Al 6061-T6 | 1 | Ø161,1 × 151,2 | MP-6061-TUBO-P1-PMP-08 | Ø180 × 166 | sí | taller (S-TURN-NOZ) | `P1-PMP-08_fixed_nozzle.svg` |

Límite supuesto del torno propio: **Ø 180 mm** (inputs.yaml `bom.lathe_max_d_mm`, [SUPUESTO] — **medir** volteo sobre la bancada y sobre el carro, y distancia entre puntos).
<!-- /FAB:torno -->

- **Casos al borde:** el **anillo de desgaste P1-PMP-02** (316L, barra hueca) entra en el límite supuesto pero lleva la cota más fina del jet (Ø interior = Ø de puntas + 2 × holgura = <!--V:manifest.params.D_bore:.2f-->132.79<!--/V--> mm, H7); en un torno manual liviano con 316L conviene mandarlo con la carcasa (S-TURN-HSG) o tornearlo **montado en la carcasa** para que quede concéntrico. El **eje P1-DRV-01** necesita distancia entre puntos mayor que su barra (tabla) y luneta: si no hay, a taller.
- **316L:** herramienta de metal duro positiva, avance constante, sin "frotar" (se endurece por deformación); refrigerante [ESTIMADO: práctica]. **POM-C** (bujes P1-PMP-07/11, P1-REV-03, P1-STE-03): herramienta afilada de HSS, sin refrigerante, dejar el Ø interior para el final y medir después del prensado (P1.10). **Semipasadores de corte P1-PMP-05** (<!--V:manifest.params.pmp_pin_n:-->2<!--/V--> por juego, Ø<!--V:sizing.mech.shear_pin.d_mm:.1f-->3.5<!--/V--> × <!--V:manifest.params.pmp_pin_half_len:.1f-->29.5<!--/V--> mm): de la **misma barra** 6061-T6 que los <!--V:manifest.params.pmp_pin_spares_sets:-->3<!--/V--> juegos de repuesto (R-PIN) y que los juegos de la probeta P1.9; extremos planos con chaflán chico (se tocan en el centro del eje).
- **Interfaces de la bomba (auditoría Pass 3, planos P1-PMP-01/05/06/08 y P1-INT-01):** carcasa con **espigón de centraje Ø<!--V:manifest.params.pmp_f1_spigot_d:.0f-->140<!--/V--> h6** concéntrico al asiento del anillo (una atada, TIR ≤ 0,03) y **8 × M5 ciegos** en la cara trasera (rosca <!--V:manifest.params.pmp_f2_thread_L:.0f-->9<!--/V--> mm, enmascarar en el anodizado); 2 × M5 radiales roscados en pared + saliente. Tobera con **brida Ø<!--V:manifest.params.pmp_f2_od:.1f-->161.1<!--/V-->** (más chica que el agujero del espejo), espiga <!--V:manifest.params.pmp_noz_spigot:.0f-->12<!--/V--> mm con ranura de O-ring **radial** y largo controlado (+0/+0,05: deja <!--V:manifest.params.pmp_stack_gap:.2f-->0.25<!--/V--> mm entre bridas). Estator: 2 agujeros **lisos** Ø5,5 × 3,5 (ya no roscados). Semipasadores P1-PMP-05: **2 por juego**, largo <!--V:manifest.params.pmp_pin_half_len:.1f-->29.5<!--/V--> mm.
- **Pórtico P1-DRV-03:** zapatas con **ranura de 9 mm abierta hacia popa** (no agujeros) y paso del resalte Ø<!--V:manifest.params.drv_brg_shoulder_hole:.1f-->32.5<!--/V--> (no roza el aro interior del 7204 BECBP); mecanizar el Ø47 H7 después de soldar.
- **Traba y pivote del bucket (ronda 4, torno propio; planos P1-REV-02_casquillo_pivote_bucket, P1-REV-02_munon_pivote_bucket, P1-REV-03 y P1-REV-04_embolo_*).** La caja envolvente del CAD (columna de la tabla de arriba) incluye el tornillo en P1-REV-02 y el pomo en P1-REV-04; la barra la compra la BOM con los overrides `form: bars` de `inputs.yaml bom.stock.overrides` (hallazgo 8 de §10, resuelto): **`MP-DPX-D40`** (dúplex 1.4462, ronda 5) para los casquillos del pivote (Ø36 + sobremedida) y **`MP-DPX-D22`** para los muñones (Ø20 + sobremedida; pivote en dos piezas desde la re-auditoría del cierre de la ronda 5, MECH-1), **`MP-316-D35`** para el cuerpo ajustado con su collar Ø32, la tapa y el pomo del émbolo (Ø32 + sobremedida; cierre de la ronda 5), **`MP-316-D18`** para el perno (largos y cantidad en la especificación de cada fila de `bom.csv`). La tabla de arriba muestra la barra más gruesa de cada pieza (se regenera con `tabla_fabricacion.py`, paso 6e de `run_all.py`).
  - **Pivote P1-REV-02 en dos piezas (×2 de cada una; re-auditoría del cierre de la ronda 5, MECH-1: el espaciador de una pieza no se podía montar)**, **dúplex 1.4462 (2205) +AT** con **certificado 3.1 EN 10204 (Rp0,2 ≥ 450 MPa)** (re-auditoría ronda 5, MEC-01: en 316 el muñón fluía con la precarga + la flexión; recibir los certificados, PENDIENTES P1.11):
    - *Casquillo* de barra Ø40 (`MP-DPX-D40`) [CALCULADO: brida Ø<!--V:manifest.params.REV_sp_fl_d:g-->36<!--/V--> + 2 de sobremedida → Ø38, comercial Ø40], largo 24 [CALCULADO: plano P1-REV-02_casquillo_pivote_bucket]: brida Ø<!--V:manifest.params.REV_sp_fl_d:g-->36<!--/V--> × <!--V:manifest.params.REV_sp_fl_t:g-->4<!--/V--> con la cara de apoyo plana y a escuadra con el piloto ≤ 0,02 [SUPUESTO: plano P1-REV-02_casquillo_pivote_bucket] y piloto Ø<!--V:manifest.params.REV_sp_pilot_d:g-->24<!--/V--> **h6** (más grueso que el muñón desde el cierre de la ronda 5; entra en el Ø<!--V:manifest.params.REV_sp_pilot_d:g-->24<!--/V--> H7 de la oreja y es el **camino de carga del corte y del momento del pivote**: el ajuste importa) de <!--V:manifest.params.STE_piv_t:g-->20<!--/V--> mm, el largo del lóbulo engrosado del pivote: su fondo queda **enrasado** con la cara interior del lóbulo y la arandela ancha apoya en los dos, sin puente [CALCULADO: checks de P1-REV-02; CALC-4]; agujero **Ø<!--V:manifest.params.REV_pin_d:g-->20<!--/V--> H7 ciego** desde la brida, fondo de 4 mm [SUPUESTO: `P1-REV-02.SLEEVE_BOTTOM`] con Ø12,5 pasante. Tornear piloto, cara de la brida y agujero Ø20 H7 en una atada. Va con **Loctite 641** en el piloto (llena el juego del H7/h6: FEA-4) y Tef-Gel solo en la cara de la brida (06 M13).
    - *Muñón* de barra Ø22 (`MP-DPX-D22`): tubo Ø<!--V:manifest.params.REV_pin_d:g-->20<!--/V--> **h7** Ra 0,8 (gira el buje POM) con agujero Ø12,5 pasante, largo 39,8 [CALCULADO: plano P1-REV-02_munon_pivote_bucket]: del fondo del casquillo hasta afuera del buje, bajo la arandela de la cabeza. Entra después del bucket, por el buje, con Tef-Gel.
    - Tornillería (B-PIVM12): ISO 4017 M12 × 60 A4-80 (`P1-REV-02.bolt_len_iso`), ISO 7089 bajo la cabeza sobre el extremo del muñón y, sobre el fondo del casquillo y la cara interior del lóbulo, arandela ancha ISO 7093 Ø<!--V:manifest.params.REV_washer_in.0:g-->37<!--/V--> × <!--V:manifest.params.REV_washer_in.1:g-->3<!--/V--> y tuerca **baja ISO 4035 M12 A4-035** (m <!--V:manifest.params.REV_nut_h:g-->6<!--/V--> mm [ESTIMADO: ISO 4035, m máx.; 7 mm es la DIN 439-B, MECH-9]: con ella el lóbulo de 20 mm entra con el M12 × 60; fila de carga de prueba en P1-REV-02); par <!--V:manifest.params.REV_bolt_T_Nm:g-->12<!--/V--> N·m con Loctite 243 (06 M13).
  - **Émbolo P1-REV-04 (×2)**, AISI 316, propio porque el GN 617 de catálogo no llega (research/R08b, nota 2026-10-02); **cuerpo ajustado** desde el cierre de la ronda 5 (R5-N1, D-17d). *Cuerpo* de barra Ø35 (la compra la BOM: `MP-316-D35`, Ø32 + sobremedida; override `form: bars` de P1-REV-04 en `inputs.yaml`; de la misma barra salen la tapa y el pomo): **Ø<!--V:manifest.params.REV_lock_bore_d:g-->24<!--/V--> h6** (23,987–24,000 [CALCULADO: ISO 286]) en todo su largo: el cuerpo es de un solo Ø (`_release.PLG_BODY_D`) y el tramo que queda en el lóbulo engrosado de la traba (<!--V:manifest.params.STE_lock_t:g-->23.5<!--/V--> mm, R5-N5) es el ajuste; más hacia adentro va la ranura del anillo DIN 471-24 (Ø22,9 × 1,3 [ESTIMADO: DIN 471]) a **24,6 (+0,1/0) de la cara de APOYO del collar** (lóbulo + 0,8 de la arandela + 0,3; acotada desde esa cara, no desde el extremo del collar; el juego axial lo toma el Loctite 641) [CALCULADO: plano P1-REV-04_embolo_cuerpo; re-auditoría del cierre de la ronda 5, MECH-5: sin tolerancia, con ISO 2768-m y el anodizado del lóbulo el anillo podía no entrar]; **collar exterior Ø32 × 1,5** [CALCULADO: `piezas/_release.PLG_COLLAR_D/PLG_COLLAR_T`] (apoya en la cara exterior del lóbulo, con 1 mm de luz al brazo del bucket [CALCULADO: check de P1-REV-04]) con la cara de apoyo plana y a escuadra con el Ø24 ≤ 0,02 (plano P1-REV-04_embolo_cuerpo); interior **Ø16 H8** pasante Ra 0,8 (guía del perno y, a continuación, cámara del resorte; la guía se engrasa al montar: perno 316 en guía 316, riesgo de engrane, CALC-3 y 06 §4) y rosca interior M20×1 × 6 atrás para la tapa; tornear el Ø24, la cara del collar y el interior en una atada; *tapa* M20×1 de 4 mm con agujero Ø10,2 para la cola y **2 × Ø3 para llave de gancho**; va con Loctite 243 en su rosca (MECH-7: sin agujeros ni fijador no había de dónde agarrarla y podía aflojarse). **Sin rosca en la oreja ni par de apriete:** el cuerpo entra ajustado H7/h6 con Loctite 641 desde afuera de la oreja (06 M13) y lleva la fuerza y el momento del perno por aplastamiento; ya no hay rosca M24×1,5 ni collar interior Ø36 con planos para la llave (la versión roscada a 110 N·m abría el lóbulo de la oreja: R5-N1, auditoria.md). *Perno* de barra Ø18 (`MP-316-D18`): Ø<!--V:manifest.params.REV_lock_pin_d:g-->16<!--/V--> **h9** Ra 0,8 con chaflán 1 × 45° en la punta, escalón (asiento del resorte) y cola Ø10 de **42 mm** = cámara 30 + tapa 4 + rosca del pomo 8 (`_release.PLG_TAIL_L`: el extremo de la cola apoya en el fondo del pomo; re-auditoría del cierre de la ronda 5, MECH-2: con 44 mm la punta sobresalía 3 mm y liberar se comía la carrera; DES-02/MEC-03: antes el plano sumaba la carrera y daba 56) con **rosca exterior M10×1 × 8 en el extremo** (pomo) y **rosca M4 axial de 12 mm de profundidad** (MECH-6) para el vástago M4 × 14 del eslabón rígido de P1-REV-09 (Loctite 243); **hexágono interior 6 × 6 en la punta** (MECH-7: se sostiene el perno desde afuera, por el agujero del brazo, al roscar o sacar el pomo) [plano P1-REV-04_embolo_perno]; ajuste H8/h9: juego 0–0,07 mm [CALCULADO: ISO 286, Ø16]. *Pomo* (R5-N4): AISI 316 de la barra del cuerpo (ya no POM), Ø23 × 10 (`_release.PLG_KNOB_D`: pasa por el Ø24 H7 de la oreja con 1 mm de holgura [CALCULADO: check «pomo pasa por el agujero de la oreja al montar desde afuera» de P1-REV-04]) con rosca ciega M10×1 × 8, fondo de 2 mm con agujero Ø4,5 (pasa el vástago M4 del eslabón) y 2 planos e/c 22; se rosca **a fondo** en la cola con Loctite 243 (sosteniendo el perno por el hexágono de la punta) y apoya en la tapa en reposo: su posición fija la sobresalida de la punta, 1 mm sobre la cara exterior del brazo [CALCULADO: `piezas/_release.pin_tip_y`] (plano P1-REV-04_embolo_perno). **Control en banco** (MECH-2): con el émbolo armado y el pomo apoyado en la tapa, la punta queda a 10,0 ± 0,2 de la cara exterior del collar [CALCULADO: plano P1-REV-04_embolo_perno]. Medidas en el plano y en `piezas/_release.PLG_*`; carrera <!--V:manifest.params.REV_plunger_stroke:g-->12<!--/V--> mm (liberar pide <!--V:manifest.params.REV_release_need:g-->9.5<!--/V-->). Resorte comprado (B-SPRING: alambre 1,4, Ø ext 15, 6,5 espiras útiles, largo libre 40; re-auditoría ronda 5, DES-01; medirlo al recibirlo, PENDIENTES P1.8); anillos DIN 471-24 A4 y arandelas 316 Ø24,2 × Ø32 × 0,8 (B-RING24); Loctite 243 (pomo, tapa y vástago M4) y 641 (cuerpo en la oreja y piloto del casquillo del pivote) (B-LOCK243); machos M20×1 y M10×1 y terraja M10×1 en B-TAP24 (el id conserva el nombre histórico).
  - **Buje P1-REV-03 (×2)**, POM-C de varilla Ø32 [CALCULADO: brida Ø<!--V:manifest.params.REV_bush_fl_d:g-->30<!--/V--> + 2]: exterior Ø<!--V:manifest.params.REV_bush_od:g-->24<!--/V--> con **0,05–0,10 mm de interferencia** [SUPUESTO: plano P1-REV-03] **contra el agujero real** del brazo (medirlo después de escariarlo, §4), largo <!--V:manifest.params.REV_bush_L:g-->18<!--/V-->; el interior se deja chico (Ø19,5 [SUPUESTO]) y se escaria a **Ø20,1 (+0,05/0)** DESPUÉS de prensar (el prensado cierra el agujero: R4-08). Entra en P1.10 (hinchamiento en agua) con P1-PMP-07/11.
- **Orejas del bucket en la boquilla P1-STE-01 (taller S-MILL-STE, plano P1-STE-01).** Orejas de <!--V:manifest.params.STE_ear_t:g-->14<!--/V--> mm (placa) con una extensión hacia proa a la altura del pivote (ligamento del agujero del piloto) y **lóbulos engrosados** alrededor de cada agujero (R5-N5, cierre de la ronda 5), que alargan el apoyo del piloto y del cuerpo del émbolo: el del pivote (R<!--V:manifest.params.STE_ear_r:g-->22<!--/V-->), de <!--V:manifest.params.STE_piv_t:g-->20<!--/V--> mm, solo hacia adentro (la brida del casquillo del pivote apoya en la cara exterior de la placa); el de la traba (R<!--V:manifest.params.STE_lock_lobe_r:g-->20<!--/V-->), de <!--V:manifest.params.STE_lock_t:g-->23.5<!--/V--> mm, sale 3 mm por fuera de la placa (cara exterior en |Y| = <!--V:manifest.params.STE_lock_y1:g-->55<!--/V--> mm, apoyo del collar del émbolo) y entra 6,5 mm por dentro con R<!--V:manifest.params.STE_lock_in_r:g-->18<!--/V--> (libra el ojo del eslabón del otro émbolo; más adentro llegaría al cubo del balancín) [CALCULADO: `params_direccion.py`]; en cada una, agujero del pivote **Ø<!--V:manifest.params.REV_sp_pilot_d:g-->24<!--/V--> H7 escariado** (uno por oreja: ya no pasante de lado a lado; es el apoyo del piloto del casquillo, que lleva el corte y el momento del pivote) y agujero **liso Ø<!--V:manifest.params.REV_lock_bore_d:g-->24<!--/V--> H7 escariado** del cuerpo ajustado del émbolo (el mismo Ø que el piloto: un solo escariador) a <!--V:manifest.params.REV_lock_r:g-->45<!--/V--> mm del pivote, a <!--V:manifest.params.REV_lock_ang:g-->10<!--/V-->° (+Y) y <!--V:manifest.params.REV_lock_ang_m:g-->-25<!--/V-->° (−Y) del eje X, con ligamento hasta el borde del lóbulo de 8 mm (6 mm en la parte de R18) [CALCULADO: r − Ø24/2]. Los **pies de los lóbulos** (las uniones reentrantes lóbulo–placa, en las dos caras de la placa) llevan **R1,5** [SUPUESTO: radio de pie de fabricación; re-auditoría del cierre de la ronda 5, FEA-3: vivos, son un concentrador en un ligamento de 6061 que trabaja a fatiga]. **Garganta en el tubo bajo el émbolo −Y** (el más bajo; re-auditoría del cierre de la ronda 5, MECH-3: sin ella su cuerpo Ø24 pasaba a 0,26 mm del tubo): cilindro de radio 14 coaxial con el eje de ese émbolo (radio del cuerpo 12 + luz 2 [SUPUESTO: `_release.SADDLE_CLR`]), en el tramo que recorren su cuerpo y su pomo (en reposo y tirado), de Y −29,5 a Y +22 en el marco de la boquilla [CALCULADO: `_release.saddle`]; quedan ≈ 3,3 mm de pared bajo la garganta [CALCULADO: z 62,8 − 14 contra el paso Ø91,12]; geometría en el STEP de P1-STE-01. Los dos H7 con posición ±0,1 respecto del pivote [SUPUESTO: plano P1-STE-01]: si no salen de la misma atada del CNC, con la **plantilla referida al pivote** (B-REAM16, de recortes: placa con espigón Ø<!--V:manifest.params.REV_sp_pilot_d:g-->24<!--/V--> h6 en el agujero del piloto ya escariado y casquillos guía recambiables a r 45 y al ángulo de esa oreja, uno por herramienta y F7 sobre el Ø medido de cada una —broca 23,7 y escariador Ø<!--V:manifest.params.REV_lock_bore_d:g-->24<!--/V--> H7, los mismos del piloto—, como en la plantilla del bucket de §4; orientada contra la cara mecanizada de la oreja). Ya no hay rosca M24 ni guía de roscado. Caras exteriores planas Ra 1,6 en Ø40 alrededor del pivote (placa: apoyo de la brida del casquillo) y en Ø36 alrededor de cada émbolo (lóbulo de la traba: apoyo del collar Ø32 del cuerpo) [CALCULADO: plano P1-STE-01]: **se anodizan** con el resto (no enmascarar: aíslan el 316 del 6061; 06 §4). Los agujeros Ø<!--V:manifest.params.REV_sp_pilot_d:g-->24<!--/V--> H7 del piloto y Ø<!--V:manifest.params.REV_lock_bore_d:g-->24<!--/V--> H7 del émbolo **se enmascaran** (ajustes): el piloto del casquillo y el cuerpo del émbolo llevan Loctite 641, que llena el juego y aísla el inox del agujero (06 §4; el piloto iba con Tef-Gel hasta la re-auditoría del cierre de la ronda 5, FEA-4). Las caras interiores de los lóbulos son planas: en la del pivote apoya la arandela ancha ISO 7093, junto con el fondo del casquillo, enrasado (la tuerca baja ISO 4035 va sobre la arandela); en la de cada émbolo, la arandela 316 Ø24,2 × Ø32 × 0,8 y el anillo DIN 471-24 del cuerpo (B-RING24).
- **Chapa:** lo plano sale de **corte láser/agua** (S-LASER) con los planos de `04_diseno/planos/`; el taladrado, avellanado y plegado chico (P1-CTL-01/09/14, P1-STE-04/07/08, P1-REV-09) es propio. Tolerancias generales ISO 2768-m y Ra 1,6 en asientos (rótulo de los planos).

---

## 4. Soldadura (Al 5083, 6082 y 316L)

<!-- FAB:soldadura -->
| Servicio | Qué | Especificación (bom.csv) | Cubre | EUR | Etiqueta |
|---|---|---|---|---|---|
| S-WELD-INT | Soldadura TIG Al 5083 (aporte 5183) del conducto P1-INT-01 (rampa, transición, brida de bomba, chimenea) sobre la placa base P1-INT-02 + refrentado de la cara enrasada + prueba de estanqueidad | Soldador certificado en Al; plantilla de armado; prueba con agua/jabón y aire 0,3 bar | P1-INT-01 P1-INT-02 | 480 | [ESTIMADO: 6 h × 70 €/h + aporte y gas] |
| S-WELD-AL | Soldadura TIG de piezas chicas de Al: pórtico P1-DRV-03 y soporte del motor P1-MOT-02 (6082), bucket P1-REV-01 (chapa 8 mm, aros de refuerzo del pivote 10 mm; el alojamiento del buje Ø24 H7 y los agujeros de traba Ø16,5 se hacen DESPUÉS de soldar, 05 §4), soporte Mach5 P1-REV-05 y soporte de reenvío del desbloqueo P1-REV-09 (5083), grapas de P1-CTL-08, escalón, placa lateral y pestaña de tope de P1-CTL-10; rolado de la cuchara del bucket | Aporte 5183 (5083) / 4043 o 5356 (6082); planos de 04_diseno/planos | P1-DRV-03 P1-MOT-02 P1-REV-01 P1-REV-05 P1-REV-09 P1-CTL-08 P1-CTL-10 | 355 | [ESTIMADO: 4,5 h × 70 €/h + rolado (ronda 4: + 0,5 h por P1-REV-09 y las placas de P1-CTL-10)] |
| S-WELD-316 | Soldadura TIG 316L de la rejilla P1-INT-03 (9 pletinas perfiladas + pletina de popa + tirantes) | Aporte 316LSi, plantilla para mantener el enrase; decapado/pasivado | P1-INT-03 | 140 | [ESTIMADO: 1,5 h × 70 €/h + decapado] |
| S-LASER | Corte láser / chorro de agua de las piezas de chapa (DXF de 04_diseno/planos) | 5083: placa base 10, placas de espejo/central/soporte 6, topes de dirección 8, bucket 8 (cuchara, brazos) y aros de refuerzo del pivote 10, soporte de reenvío del desbloqueo 6/8/5 (base, montante, 2 pestañas; los balancines se fresan de placa 12, B-RELKIT), brida yugo 20, brazo 10, conducto 5/12; 6061: palancas 8, gatillo 6, placa lateral del gatillo 4 y pestaña de tope 5 (P1-CTL-10); 6082: pórtico 12, soporte motor 10; 316: pletinas de rejilla 4 | P1-INT-01 P1-INT-02 P1-INT-03 P1-CTL-01 P1-CTL-08 P1-CTL-09 P1-CTL-10 P1-CTL-14 P1-REV-01 P1-REV-05 P1-REV-09 P1-STE-04 P1-STE-07 P1-STE-08 P1-DRV-03 P1-MOT-02 | 290 | [ESTIMADO: preparación 50 € + ≈ 12 €/pieza; ronda 4: + 6 piezas chicas del desbloqueo (base, montante y 2 pestañas de P1-REV-09; placa lateral y pestaña de P1-CTL-10) ≈ + 70 €] |
<!-- /FAB:soldadura -->

**Procedimiento para el taller** (conducto P1-INT-01 sobre placa base P1-INT-02, bucket P1-REV-01, soporte P1-REV-05, grapas de P1-CTL-08):
- **Proceso:** TIG en **corriente alterna** (limpia el óxido) con aporte **ER5183** para 5083 (la BOM lo fija); MIG pulsado con 5183 es aceptable para las costuras largas del conducto si el taller lo domina [ESTIMADO: práctica de soldadura de aluminio naval; confirmar con el soldador]. 6082 (pórtico P1-DRV-03, soporte del motor P1-MOT-02): 5356 o 4043 (BOM). Rejilla 316L: TIG con 316LSi, decapado y pasivado (S-WELD-316); el diseño actual tiene **<!--V:manifest.params.grille_bars:-->9<!--/V--> pletinas** con luz de <!--V:manifest.params.toma_bar_gap:.2f-->12.24<!--/V--> mm y **no se suelda a la toma**: va aislada del 5083 con camisa/cinta de PTFE en las ranuras (06 §4), sin contacto metálico 316 ↔ 5083.
- **Preparación:** desengrasar, cepillo de **inox dedicado** al aluminio justo antes de soldar, punteado en **plantilla** (el enrase de la placa base con el casco y la concentricidad de la brida de la bomba importan más que la estética); chapas de 5 mm sin precalentar [ESTIMADO].
- **Secuencia del conducto:** puntear todo → costuras cortas alternadas para no torcer la brida → **refrentar la brida de la bomba, la brida de la chimenea y la cara enrasada después de soldar** (la BOM incluye el refrentado en S-WELD-INT). **Mecanizar después de soldar, en una atada:** cara y **rebaje de centraje Ø<!--V:manifest.params.pmp_f1_spigot_d:.0f-->140<!--/V--> H7** de la brida de la bomba, 8 agujeros, buje del sello Ø<!--V:manifest.params.seal_spigot_d:.0f-->42<!--/V--> H8 con sus 4 × M6 y cara de la chimenea; coaxialidad rebaje ↔ buje ≤ 0,05 (plano `P1-INT-01_conducto.svg`). Las ranuras de la rejilla llevan <!--V:manifest.params.toma_iso_gap:.1f-->0.5<!--/V--> mm por lado para la camisa de PTFE.
- **Alivio de tensiones: no se hace en 5083** [ESTIMADO: 5083 es una aleación no tratable térmicamente (H111, endurecida por deformación); un tratamiento de alivio o un mantenimiento prolongado a 65–200 °C puede **sensibilizar** las aleaciones 5xxx con > 3 % Mg a corrosión intergranular — **verificar** con el soldador / ficha del material]. La resistencia en la zona afectada por el calor (ZAT) ya está considerada: `structural_toma.py` y `structural_direccion.py` usan el Rp0,2 del 5083-O/H111 (= ZAT) y FAT 25 en las costuras; `structural_tren.py` usa el admisible de ZAT del 6082-T6 en el pórtico y el soporte del motor.
- **Bucket P1-REV-01 (ronda 4: criterio de traba única).** Cada traba sola lleva todo M_h (<!--V:est.loads.structural_direccion.M_hinge_Nm:.1f-->135.3<!--/V--> N·m con la reversa R12 [CALCULADO]; <!--V:est.loads.structural_direccion.F_lock_pin_N:.0f-->3006<!--/V--> N en el perno): la resistencia ya no depende de que los agujeros de los dos brazos coincidan, así que se eliminó el taladrado coincidente con el bucket montado y la prueba con comparador. Secuencia:
  1. **Corte (S-LASER):** cuchara (desarrollo) y brazos en chapa 5083 de <!--V:manifest.params.REV_t:g-->8<!--/V--> mm; 2 aros de refuerzo de <!--V:manifest.params.REV_ring_t:g-->10<!--/V--> mm (MP-5083-AROS) de radio <!--V:manifest.params.REV_boss_r:g-->20<!--/V--> mm (Ø40 [CALCULADO: 2 × REV_boss_r]). El agujero del buje sale del láser **chico** (Ø22 [SUPUESTO]) en brazos y aros; los agujeros de traba **no** se cortan (o solo un piloto ≤ Ø12 [SUPUESTO] que la broca se come).
  2. **Soldadura (S-WELD-AL):** cuchara rolada y brazos en la plantilla de armado en posición ABAJO (plano P1-REV-01_bucket_cuchara); cada aro en la cara exterior de su brazo, centrado con un perno en los agujeros chicos. TIG con ER5183.
  3. **Alojamiento del buje Ø<!--V:manifest.params.REV_bush_od:g-->24<!--/V--> H7, DESPUÉS de soldar:** broca 23,7 y escariador largo Ø24 H7 (B-REAM16) **de una pasada por los dos brazos** (brazo + aro), el segundo guiado por el primero, o los dos en una atada en la fresadora. Control: un perno patrón Ø24 h6 pasa por los dos a la vez. **Caras interiores de los brazos en la zona de las trabas** (re-auditoría del cierre de la ronda 5, MECH-8): después de soldar, planas y a escuadra con el eje del buje ≤ 0,3 mm [SUPUESTO: tolerancia de la re-auditoría], medidas contra el perno patrón: el collar del émbolo queda a 1,0 mm del brazo [CALCULADO: check de P1-REV-04] y una distorsión angular de la soldadura de ≈ 1,3° consume ese milímetro [CALCULADO: re-auditoría del cierre]; T0.M6 lo verifica con galga en todo el giro (06).
  4. **Agujeros de traba Ø<!--V:manifest.params.REV_lock_hole_d:g-->16.5<!--/V-->, con plantilla referida al agujero del buje** (los 4: ARRIBA y ABAJO en los dos brazos). Plantilla (B-REAM16, de recortes): una placa de acero o Al de ≈ 10 mm por brazo, con espigón **Ø24 h6** que entra en el alojamiento recién escariado y **2 puestos de casquillo** (casquillo portador fijo + casquillos guía recambiables tipo DIN 173: uno con el agujero de la broca 16,2 y otro con el del escariador, cada uno F7 sobre el Ø **medido** de su herramienta; un escariador para Ø16,5 +0,1/0 no pasa por un casquillo de Ø16,5 nominal: auditoría ronda 4, M2) a <!--V:manifest.params.REV_lock_r:g-->45<!--/V--> mm del centro: uno en el ángulo de la traba ABAJO de ese brazo (<!--V:manifest.params.REV_lock_ang:g-->10<!--/V-->° en el +Y, <!--V:manifest.params.REV_lock_ang_m:g-->-25<!--/V-->° en el −Y, marco de la boquilla con el bucket ABAJO) y otro girado <!--V:manifest.params.bucket_down_deg:g-->70<!--/V-->° alrededor del centro (traba ARRIBA): coordenadas de los planos P1-REV-01_bucket_brazo_estribor / _babor. Las dos placas van fijas a un mandril Ø24 h6 que pasa por los dos brazos (pasador o chaveta entre placa y mandril), así quedan **en fase** entre sí; la orientación del conjunto se toma del contorno del brazo con una escuadra (el ángulo absoluto solo cambia la posición del bucket trabado, no la resistencia). Broca 16,2 por su casquillo; cambiar el casquillo sin mover la plantilla y escariador Ø16,5 (+0,1/0) por el suyo.
     **Tolerancia de posición ±0,2 mm** respecto del centro del buje [SUPUESTO: plano P1-REV-01]: alcanza porque el juego perno ↔ agujero es <!--V:manifest.params.REV_lock_hole_d:g-->16.5<!--/V--> − <!--V:manifest.params.REV_lock_pin_d:g-->16<!--/V--> = 0,5 mm en el diámetro [CALCULADO], el bucket gira libre en su pivote hasta que entra el primer perno y el chaflán 1 × 45° del perno centra el resto, y porque la resistencia ya no depende del reparto entre trabas. Lo que sí tiene que cumplirse —que **entren los dos pernos** ARRIBA y ABAJO— lo comprueba la prueba funcional de 06 (T0.M6b).
  5. **Buje P1-REV-03:** medir el Ø24 real; tornear el exterior del buje con 0,05–0,10 mm de interferencia (§3), prensar con prensa de husillo (sin golpes) y **escariar el interior a Ø20,1 (+0,05/0) con el buje ya prensado**, los dos brazos de una pasada. El muñón de P1-REV-02 (Ø<!--V:manifest.params.REV_pin_d:g-->20<!--/V--> h7) tiene que girar a mano en los dos bujes. Después, P1.10.
- **Prueba de estanqueidad del conducto (antes de instalarlo):** tapar la brida de la bomba y la boca de la toma con placas + goma; la BOM pide **aire a 0,3 bar con agua jabonosa** (S-WELD-INT) → 0 burbujas en las costuras en 10 min [SUPUESTO: tiempo]. **Ojo:** 0,3 bar es menos que la presión de cierre <!--V:sizing.loads.p_pump_max_Pa:.0f-->67234<!--/V--> Pa y que el golpe de fondo <!--V:est.loads.structural_toma.p_slam_Pa:.0f-->50000<!--/V--> Pa que ve el conducto: sirve para encontrar poros, no como prueba de resistencia. Recomendado además: **prueba hidrostática con agua** a 1,5 × la presión de cierre, 15 min, sin gotas [SUPUESTO: mismo criterio que P1.11; ver §10].

---

## 5. CNC 5 ejes: impulsor y estator

<!-- FAB:cnc -->
| Pieza | Qué es | Qué mandar | Cotas críticas | Balanceo |
|---|---|---|---|---|
| Impulsor P1-PMP-03 | AISI 316; 5 álabes; Ø132,0 punta, cubo Ø66,0; masa CAD 1 335 g | `04_diseno/step/P1-PMP-03_impeller.step` + `P1-PMP-03_impeller_hub.svg`, `P1-PMP-03_tabla_angulos_alabes.svg` | Ø de puntas torneado a medida del anillo: holgura radial 0,40 mm (Ø anillo 132,79); agujero del eje y agujero del pasador según plano del cubo | G6.3 a 4 182 rpm: e_per = 14,4 µm → U_per = 19,2 g·mm (dos planos: la mitad por plano) |
| Estator P1-PMP-06 | Al 6061-T6; 7 álabes + camisa + cubo; masa CAD 1 524 g | `04_diseno/step/P1-PMP-06_stator.step` + `P1-PMP-06_stator.svg` | alojamiento del buje P1-PMP-07 (H7) y bridas según plano; anodizado duro después (S-ANOD) | no gira: sin balanceo |

| Sección | r [mm] | U [m/s] | β1 flujo [°] | β2 flujo [°] | Entrada al estator [°] | de Haller |
|---|---|---|---|---|---|---|
| cubo | 33,0 | 17,5 | 28,0 | 41,3 | 53,5 | 0,71 |
| medio | 52,2 | 27,7 | 18,6 | 21,8 | 64,9 | 0,86 |
| punta | 66,0 | 35,1 | 14,9 | 16,5 | 69,7 | 0,91 |

Ángulos de flujo de `resultados/sizing.json` (pump.sections, desde la tangencial); los de **pala** (con incidencia y desviación) están en `P1-PMP-03_tabla_angulos_alabes.svg`, que es lo que se manda.

| Servicio | Qué | EUR | Etiqueta |
|---|---|---|---|
| S-CNC-IMP | Impulsor 316L CNC 5 ejes, 1 u., con material, torneado del Ø exterior contra el anillo de desgaste y balanceo | 1 050 | [ESTIMADO: research/R11 §6 — CNC 5 ejes inox 600–1500 € (punto medio)] |
| S-CNC-STAT | Estator Al 6061-T6 CNC 5 ejes (7 álabes + camisa + cubo), 1 u., con material | 630 | [ESTIMADO: research/R11 §6 — Al ≈ 40 % menos que inox: 360–900 € (punto medio)] |
<!-- /FAB:cnc -->

**Qué mandar al taller** (S-CNC-IMP / S-CNC-STAT; cotizar con Xometry, Protolabs, JLCCNC o un taller UE [ESTIMADO: research/R11 §6]):
1. **STEP** de `04_diseno/step/` (P1-PMP-03 impulsor y P1-PMP-06 estator): es la geometría que manda.
2. **Tabla de ángulos de los álabes** `04_diseno/planos/P1-PMP-03_tabla_angulos_alabes.svg` (β de pala en cubo/medio/punta, cuerda, espesor, apilado) para que el programador controle la superficie, y los planos del cubo y del estator (`P1-PMP-03_impeller_hub.svg`, `P1-PMP-06_stator.svg`) con los asientos.
3. **Material:** impulsor **AISI 316L** (no 1.4301: no apto sumergido, research/R08b §2); estator **Al 6061-T6**, después **anodizado duro** (§6).
4. **Tolerancias:** generales ISO 2768-m; superficies de álabe ±0,2 mm de perfil y Ra ≤ 3,2 µm [ESTIMADO: práctica de impulsores chicos; acordar con el taller]; agujero del eje H7 y agujero transversal del pasador escariado a Ø<!--V:sizing.mech.shear_pin.d_mm:.1f-->3.5<!--/V--> + 0,05 (plano del cubo); **Ø de puntas con sobremedida**, a tornear al final contra el anillo de desgaste ya montado para dejar la holgura radial de <!--V:sizing.pump.tip_clearance_mm:.2f-->0.40<!--/V--> mm (P1.12).
5. **Balanceo dinámico G6.3** en dos planos a la velocidad máxima <!--V:sizing.mech.n_max_rpm:.0f-->4182<!--/V--> rpm (ISO 21940-11, grado usual de impulsores de bomba [ESTIMADO: verificar con el taller]); la tabla da la excentricidad y el desbalance residual admisibles con la masa del CAD. Corregir quitando material en el cubo, no en los álabes.

**Alternativa SLM 316L + torneado** (research/R11 §6): JLC3DP imprime 316L en 390 × 390 × 290 mm con ±0,3 mm o 0,4 %, Ra 3,2–12 µm, en ~72 h [VERIFICADO: R11 §6]; ≈ 330–610 € con el torneado del Ø exterior, del agujero y el balanceo [ESTIMADO: R11 §9]. Exige sobremedida en Ø de puntas, cubo y agujero para tornear después [SUPUESTO: 0,5 mm], granallado/pulido de los álabes (la rugosidad de SLM suma pérdidas) y los mismos controles: P1.12 y balanceo.

---

## 6. Anodizado duro y aislamiento galvánico

<!-- FAB:anodizado -->
| Ítem (bom.csv) | Qué | Especificación | Piezas | EUR | Etiqueta |
|---|---|---|---|---|---|
| B-TEFGEL | Antigalvánico Tikal Tef-Gel 60 g (todo A4/316 en contacto con Al: bridas, asientos, roscas) | PTFE, apto agua de mar | — | 42 | [VERIFICADO: research/R08b §6 — 41,89 €] |
| B-ISOW | Arandelas aislantes de fibra/nylon M3–M12 (200 u.) | Biltema art. 191083 | — | 11 | [VERIFICADO: research/R08b §6 — 84,90 kr] |
| B-ANODE | Ánodo de sacrificio de aluminio de placa atornillado a la carcasa/conducto (planos de la bomba: R06 §0, R10b H21) | Ánodo de Al (no Zn en agua salobre) ≈ 100 × 50 × 10, con espárragos; continuidad eléctrica con la carcasa | — | 20 | [ESTIMADO: research/R08b §6 — ánodo de eje Tecnoseal 96 kr VERIFICADO; de placa ≈ 15–25 €] |
| S-ANOD | Anodizado duro tipo III ~50 µm (lote): carcasa P1-PMP-01, estator P1-PMP-06, tobera P1-PMP-08, boquilla P1-STE-01, poste P1-STE-06 | MIL-A-8625 tipo III, sellado; enmascarar roscas, asientos H7 y ranuras de O-ring. Material incluido en el servicio [CALCULADO del bbox]: P1-PMP-06 168,8 × 142,8 × 142,8 → barra Al 6061-T6 (alt. 6082-T6) Ø150 × 184 mm | P1-PMP-01 (Al 6061-T6), P1-PMP-06 (Al 6061-T6), P1-PMP-08 (Al 6061-T6), P1-STE-01 (Al 6061-T6), P1-STE-06 (Al 6061-T6) | 220 | [ESTIMADO: mínimo de facturación de lote 150–300 €] |
<!-- /FAB:anodizado -->

- **Par galvánico:** 316 pasivo vs. aluminio en agua salobre ≈ 670 mV de diferencia, contra ~200 mV de límite práctico [VERIFICADO: research/R06 §0/§6; R10b H21 lo marca como riesgo medio]. El ánodo es el aluminio (carcasa, estator, tobera, conducto) y el cátodo es el impulsor + anillo de 316.
- **Anodizado duro tipo III** (~50 µm, sellado) de carcasa, estator, tobera, boquilla y poste (S-ANOD): aísla y resiste la erosión. **Enmascarar** roscas, asientos H7 y ranuras de O-ring (en la boquilla, los agujeros Ø<!--V:manifest.params.REV_sp_pilot_d:g-->24<!--/V--> H7 de los pilotos y Ø<!--V:manifest.params.REV_lock_bore_d:g-->24<!--/V--> H7 de los cuerpos de émbolo; las caras de apoyo de las bridas y de los collares, no: §3); la capa crece en parte hacia afuera [ESTIMADO: pedir al anodizador el crecimiento por cara] → los asientos que no se enmascaran se mecanizan con esa compensación. Anodizar **después** de todo mecanizado y **antes** del montaje y de la prueba hidrostática P1.11.
- **Tef-Gel** en **toda** rosca, asiento y cara de contacto 316/A4 ↔ Al (bridas de la bomba, anillo de desgaste en la carcasa, espárragos del pórtico, pernos de la boquilla) [VERIFICADO: R06 §6 "ideal to isolate and separate dissimilar materials such as Aluminium and Stainless Steel"]. **Excepciones:** el cuerpo ajustado de los émbolos P1-REV-04 va en su agujero Ø<!--V:manifest.params.REV_lock_bore_d:g-->24<!--/V--> H7 (enmascarado) con **Loctite 641** (B-LOCK243) y sin Tef-Gel: el retenedor llena el juego del ajuste H7/h6, evita el desgaste por roce y aísla el 316 del agujero sin anodizar; el collar exterior y la arandela interior apoyan en caras anodizadas (06 §4; cierre de la ronda 5, R5-N1: antes era una rosca M24×1,5 con Loctite 243 y par calculado con fijador). La rosca del M12 de los pivotes P1-REV-02 va con **Loctite 243** (par <!--V:manifest.params.REV_bolt_T_Nm:g-->12<!--/V--> N·m calculado con fijador); el piloto Ø<!--V:manifest.params.REV_sp_pilot_d:g-->24<!--/V--> H7/h6 de los casquillos del pivote va con **Loctite 641**, como el cuerpo de los émbolos (llena el juego, así que no hay roce ni fretting en el agujero enmascarado: re-auditoría del cierre de la ronda 5, FEA-4), y Tef-Gel solo en la cara de la brida y en el muñón (dúplex en el casquillo y en el buje POM).
- **Arandelas aislantes** (fibra/nylon, B-ISOW) bajo cabezas y tuercas A4 sobre Al; **bujes POM** entre pernos 316 y orejas de Al (P1-PMP-11, P1-REV-03, P1-STE-03).
- **Ánodo de aluminio** (no zinc, no magnesio en agua salobre [VERIFICADO: R06 §6]) atornillado a la carcasa/conducto con **continuidad eléctrica** medida con multímetro (< 1 Ω [SUPUESTO]); cambiar al 50 % consumido o cada año [VERIFICADO: R06 §6, Fisheries Supply].
- Las piezas de 5083 sin anodizar (conducto, placa base, placas) son aleación marina: se dejan desnudas o con imprimación epoxi marina; nunca antifouling con cobre sobre aluminio [ESTIMADO].

---

## 7. Probetas y ensayos de taller (`04_diseno/probetas/`)

`python 04_diseno/probetas/build_probetas.py` construye las probetas impresas (STEP + STL en orientación de impresión en `step/` y `stl/`), registra los ensayos de taller, escribe `probetas_manifest.json` (envolvente, masa, malla cerrada, cotas verificadas y criterios con números) y regenera estas tablas. Cada módulo `PRB-P1.x_*.py` lee la geometría de `04_diseno/piezas/` y las cargas de `sizing.json` / `estructural.json`: si cambia el diseño, cambian las probetas y sus criterios. Se eliminaron las probetas de la cola larga (rodamiento en PETG, tuerca M6 de la horquilla, barras de flexión, cuello del patín).

### 7.1 Probetas impresas

<!-- FAB:probetas -->
| Ensayo | Archivo (step/ y stl/) | Perfil (ajustes por objeto) | Cant. | Envolvente [mm] | g c/u | h c/u (PrusaSlicer) | Malla cerrada | Descripción |
|---|---|---|---|---|---|---|---|---|
| P1.1 | `P1.1A_peine_agujeros` | estructural (fill_density=100%, fill_pattern=rectilinear) | 1 | 152×111×8 | 52,3 | 5,2 | sí | Agujeros Ø(d+c) de eje vertical para Ø5, Ø6, Ø22; holguras +.15, +.20, +.25, +.30 mm + las del CAD por Ø; bolsillos hexagonales M6: e/c del CAD +.1, +.2, +.3, +.4 |
| P1.1 | `P1.1H_agujeros_horizontales` | estructural (fill_density=100%, fill_pattern=rectilinear) | 1 | 106×26×34 | 24,7 | 2,6 | sí | Agujeros horizontales Ø(d+c) para Ø16 (los que las piezas reales imprimen acostados) |
| P1.4 | `P1.4_inserto_M5` | cubiertas (brim_width=5) | 3 | 21×15×32 | 6,6 | 0,9 | sí | Recorte del nervio de P1-ELE-01 (20 × 12 mm + pared 3.2) con el agujero de inserto Ø6.4 × 10.5; pasador de tiro Ø8.4 |
| P1.6 | `P1.6A_caja_brida` | sellado | 1 | 120×120×38 | 214,9 | 23,4 | sí | Vaso Ø72 × 38 con brida Ø120 × 10 (hace de chimenea), boca Ø60, 4 × M6 en Ø100, válvula de neumático Ø11.5 en el piso |
| P1.6 | `P1.6B_tapa_oring_purga` | sellado | 1 | 120×120×19 | 183,6 | 19,8 | sí | Tapa Ø120 × 13 (= espesor de P1-INT-04), ranura 2.65 × 4.73 en r = 38.4, resalte de purga Ø26 con tuerca M6 cautiva, 4 × M6 |
| P1.7 | `P1.7A_cubo_absorcion_A` | sellado | 1 | 20×20×21 | 10,2 | 1,2 | sí | Cubo 20 mm rotulado A |
| P1.7 | `P1.7B_cubo_absorcion_B` | sellado | 1 | 20×20×21 | 10,2 | 1,2 | sí | Cubo 20 mm rotulado B |
| P1.7 | `P1.7C_cubo_absorcion_C` | sellado | 1 | 20×20×21 | 10,2 | 1,2 | sí | Cubo 20 mm rotulado C |
<!-- /FAB:probetas -->

### 7.2 Criterios pasa / no-pasa (generado)

<!-- FAB:ensayos -->
| Ensayo | Tipo | Qué se ensaya | Piezas | Pasa si (números de los JSON) | Cotas/coherencia verificadas en software |
|---|---|---|---|---|---|
| P1.1 | impresa (CAD) | Peine de holguras (Ø reales de las piezas impresas) | P1-INT-04, P1-ELE-01, P1-ELE-02, P1-CTL-02, P1-CTL-03 | El agujero rotulado con la holgura del CAD mide d + c_CAD ± 0,10 mm y la pieza real entra a mano; la tuerca M6 entra en la fila del CAD y no cae al dar vuelta la probeta. Si no: la holgura a usar es la menor fila que acepta la pieza → corregir el CAD (inputs.yaml geometry.clearance_mm / bolt_clearance_mm) antes de imprimir las piezas. | 9/9 OK |
| P1.4 | impresa (CAD) | Inserto térmico M5 inox en el nervio de P1-ELE-01 | P1-ELE-01, P1-ELE-02 | Las 3 resisten ≥ 120 N (= FS 3 × 40 N por inserto, estructural.json) sin arrancar y el inserto no gira con ≥ 4 N·m (2 × apriete M5 sobre PETG) [SUPUESTO: criterio de giro]. A ras ±0,2 mm, sin fisura alrededor (lupa 10×). | 3/3 OK |
| P1.6 | impresa (CAD) | Tapa con O-ring de cara y purga (réplica de P1-INT-04) a la presión de la chimenea | P1-INT-04, P1-INT-01 | En (1), (2) y (3): caída ≤ 10 % de la presión de ensayo en 15 min, 0 gotas en el O-ring y en la purga (papel tisú alrededor) y sin burbujas con agua jabonosa; sin fisura ni blanqueo en el resalte de la purga. Si gotea: separar O-ring / purga / poros repitiendo con la purga sellada con teflón. | 10/10 OK |
| P1.7 | impresa (CAD) | Absorción de agua (perfil de P1-INT-04) | P1-INT-04 | Ganancia (m7 − m0)/m0 ≤ 1 % en los 3 cubos. Referencia: PETG macizo ~0,3 % a saturación [VERIFICADO: research/R05 S11]; impreso absorbe más por porosidad [VERIFICADO: R05 S14]. | 1/1 OK |
| P1.9 | taller (sin CAD) | Semipasadores de corte (juego de 2) en dispositivo de corte doble | P1-PMP-05, P1-PMP-03, P1-DRV-01 | Los 3 juegos cortan entre 26,8 y 40,2 N·m (0,8–1,2 × T_cut) = 54–80 N en el brazo, con las 2 secciones cortadas en la cara muñón ↔ manguito (una por semipasador) y los restos salen con el botador. Si cortan abajo: barra más blanda (no T6) → cambiar de barra; si cortan arriba: no subir el Ø, revisar material y agujeros (filo vivo); si un solo semipasador corta: agujeros desalineados. | 5/5 OK |
| P1.10 | taller (sin CAD) | Hinchamiento de los bujes POM-C a 48 h en agua | P1-PMP-07, P1-PMP-11 | P1-PMP-07: Ø int a 48 h ≥ Ø eje P1-DRV-01 medido + 0,10 mm (≥ 20,10 con Ø nominal 20; CAD 20,2); P1-PMP-11: Ø int a 48 h ≥ Ø perno con hombro de dirección medido + 0,05 mm (≥ 8,05 con Ø nominal 8; CAD 8,1). Si no: repasar el Ø int con escariador al Ø del CAD y repetir. | 2/2 OK |
| P1.11 | taller (sin CAD) | Prueba hidrostática de carcasa + estator + tobera | P1-PMP-01, P1-PMP-02, P1-PMP-06, P1-PMP-08 | A 0,30 MPa (3,0 bar) durante 15 min: caída ≤ 2 %, 0 gotas en la brida de entrada, en la luz entre bridas carcasa ↔ tobera (O-ring radial), en el puerto y en los tornillos anti-rotación del estator (papel tisú), y deformación permanente del Ø del asiento ≤ 0,02 mm. Sin aire en la prueba (seguridad: una prueba con aire guarda energía). | 5/5 OK |
| P1.12 | taller (sin CAD) | Holgura de punta impulsor ↔ anillo de desgaste | P1-PMP-02, P1-PMP-03 | Todas las lecturas entre 0,30 y 0,40 mm y diferencia máx. − mín. ≤ 0,05 mm; el impulsor gira sin roce. Menor: repasar el anillo (no el impulsor); mayor: anillo nuevo (el anillo es la pieza de desgaste). | 2/2 OK |
<!-- /FAB:ensayos -->

Datos de partida de los criterios: <!--V:manifest.params.pmp_pin_n:-->2<!--/V--> semipasadores por juego (cada uno cruza una vez la superficie del eje: 2 secciones de corte, como el pasador pasante de sizing), Ø<!--V:sizing.mech.shear_pin.d_mm:.1f-->3.5<!--/V--> mm de <!--V:sizing.mech.shear_pin.material:-->Al 6061-T6<!--/V-->, corte de diseño <!--V:sizing.mech.shear_pin.T_cut_Nm:.1f-->33.5<!--/V--> N·m contra <!--V:est.loads.structural_bomba.loads_used.T_ctrl:.1f-->18.6<!--/V--> N·m máximos del controlador; presión de diseño de la bomba <!--V:est.loads.structural_bomba.loads_used.p_design_Pa:.0f-->200000<!--/V--> Pa (prueba × 1,5, research/R12 §7.2); presión de la chimenea <!--V:est.loads.structural_toma.p_max_Pa:.0f-->67234<!--/V--> Pa; holgura de punta <!--V:sizing.pump.tip_clearance_mm:.3f-->0.396<!--/V--> mm sobre Ø<!--V:sizing.pump.D_mm:-->132<!--/V--> mm.

### 7.3 Procedimientos

<!-- FAB:procedimientos -->
- **P1.1 — Peine de holguras (Ø reales de las piezas impresas)** (impresa). Medir cada agujero con pernos patrón (vástagos de broca) o calibre; probar la pieza real: tornillo M5/M6 A4, cuerpo del prensaestopas M16, cuerpo del interruptor de cordón y de la seta (Ø22), tuerca ISO 4032 M6 A4 en los hexágonos (empujada con el pulgar desde la cara de cama).
- **P1.4 — Inserto térmico M5 inox en el nervio de P1-ELE-01** (impresa). Tornillo M5 A4 con cáncamo en el inserto; pasador M8 en el agujero inferior a una horquilla fija; tirar con dinamómetro a ~10 N/s. 3 probetas. Además: torque de giro del inserto con llave dinamométrica (o brazo + dinamómetro). *Instalación:* Inserto M5 de inox 300 (en zona húmeda solo inox: latón se descinfica, research/R05 A10.2) [VERIFICADO: research/R05 S29 existen]; soldador a ~250–260 °C [ESTIMADO: research/R05 A10.3]; hundir el 90 % con la punta y el resto con herramienta plana [VERIFICADO: R05 S28].
- **P1.6 — Tapa con O-ring de cara y purga (réplica de P1-INT-04) a la presión de la chimenea** (impresa). Medir ranura (profundidad y ancho) y planitud de las dos caras de sello (regla + galgas). Cordón NBR70 con empalme a tope y grasa de silicona; 4 × M6 A4 con arandela ancha apretados a mano (perillas, como INT-04); purga M6 × 12 con arandela de estanqueidad. Conjunto con la tapa arriba (como en el bote), apoyado en dos listones (la válvula queda abajo); un dedo de agua adentro para mojar el O-ring. (1) +p con inflador con manómetro, 15 min, agua jabonosa por fuera; (2) −p con bomba de vacío manual (válvula sin obús), 15 min; (3) 20 ciclos abrir/cerrar tapa y purga, repetir (1). Con aire la energía guardada es chica (cavidad 56 cm³: p·V = 3,8 J [CALCULADO]); igual, gafas.
- **P1.7 — Absorción de agua (perfil de P1-INT-04)** (impresa). Acondicionar 48 h con desecante (no secar a 65 °C: Tg ~69 °C); pesar m0 (balanza 0,01 g). Sumergir 7 días en agua con 25 g/L de sal a temperatura ambiente; secar la superficie con papel y pesar m7 en < 1 min. Opcional: seguir a 30 días (saturación en semanas, research/R05 A2). *Si no pasa:* Revisar secado del filamento y solape relleno–perímetro del perfil sellado; la tapa es reemplazable (el CAD está) — inspeccionarla cada temporada.
- **P1.9 — Semipasadores de corte (juego de 2) en dispositivo de corte doble** (taller). Tornear 3 juegos de 2 semipasadores Ø3,5 × 29,5 de la misma barra que los 3 juegos de repuesto (medir Ø con micrómetro y largo con calibre). Muñón Ø20 en la morsa; manguito Ø60 exterior con agujero Ø20 H7; agujero transversal Ø3,55 pasante en muñón y manguito (taladro + escariador, alineados juntos). Meter un semipasador desde cada lado hasta que se toquen en el centro (enrasados con el Ø exterior del manguito). Tirar del brazo de 500 mm con el dinamómetro, despacio (~10 s hasta el corte); anotar F máx. Después: sacar los restos con un botador corto desde un lado (es el procedimiento de cambio en el eje real).
- **P1.10 — Hinchamiento de los bujes POM-C a 48 h en agua** (taller). Tornear los bujes, prensarlos en su alojamiento definitivo (estator / orejas de la placa de espejo, ya anodizados). Medir Ø int en 3 alturas × 2 direcciones con pernos patrón o alesómetro, y el Ø real del eje/perno con micrómetro. Sumergir el conjunto 48 h en agua del lugar a temperatura ambiente; secar y medir dentro de 10 min. El eje/perno real tiene que girar a mano sin puntos duros.
- **P1.11 — Prueba hidrostática de carcasa + estator + tobera** (taller). Armar carcasa + anillo + estator; O-ring radial engrasado (silicona) en la espiga de la tobera, meterla en el asiento sin pellizcarlo (chaflán de entrada) y apretar los 8 × M5 en cruz; medir con galgas la luz entre bridas (diseño 0,25 mm, igual en los 8 tornillos: si es 0, la espiga no aprieta la camisa del estator). Entrada: brida ciega con rebaje H7 para el espigón Ø140 y O-ring de cara. Salida Ø87,1: tapón con O-ring radial y varilla roscada central M5 A4-70 hasta la brida ciega de entrada: pasa por el agujero Ø6 de la punta del cono de cola del estator y por el buje (sin impulsor); carga del tapón 1788 N a p_ensayo → σ = 126 MPa sobre A_s 14,2 mm², FS 3,6 contra Rp0,2 del A4-70. Tuercas con arandela de estanqueidad (bonded) en el tapón y en la brida ciega. Alternativa sin varilla: yugo exterior que apoya el tapón contra el resalte de la tobera. Medir el Ø del asiento del anillo antes. Llenar de agua purgando el aire por el puerto G1/8 (arriba); bomba de prueba hidrostática manual (o bomba de engrase + manómetro 0–6 bar). Subir en 3 escalones, retener 15 min a p_ensayo, bajar, desarmar y medir el asiento.
- **P1.12 — Holgura de punta impulsor ↔ anillo de desgaste** (taller). Anillo montado en la carcasa; impulsor en el eje con rodamientos y pasador. Galgas de espesores entre la punta de cada uno de los 5 álabes y el anillo, en la entrada, al medio y a la salida de la punta, girando a mano; repetir en 4 posiciones angulares del eje. Control cruzado: Ø del anillo con alesómetro y Ø de puntas del impulsor en el torno (reloj comparador sobre mandril).
<!-- /FAB:procedimientos -->

**Banco común:** dinamómetro con palanca de madera dura (F_probeta = relación de brazos × F_dinamómetro − tara) para P1.4; brazo sobre el manguito (con un juego de semipasadores, uno desde cada lado) para P1.9; inflador con manómetro y bomba de vacío manual de purgar frenos para P1.6; bomba de prueba hidrostática manual (o bomba de engrase + manómetro 0–6 bar) para P1.11; galgas de espesores, alesómetro y micrómetro para P1.10/P1.12. Anotar cada resultado con fecha, lote de filamento/barra y foto.

### 7.4 Ajustes que usa el CAD (escaneo de las piezas impresas en orientación de impresión)

<!-- FAB:ajustes -->
| Pieza | Nominal | Ø / e/c en CAD [mm] | Holgura CAD [mm] | Eje en impresión | Se calibra con |
|---|---|---|---|---|---|
| P1-CTL-02 | Ø5 | 5,50 | +0,50 | vertical | P1.1A |
| P1-CTL-03 | Ø5 | 5,50 | +0,50 | vertical | P1.1A |
| P1-ELE-02 | Ø5 | 5,50 | +0,50 | vertical | P1.1A |
| P1-ELE-01 | Ø6 | 6,40 | +0,40 | vertical | P1.1A |
| P1-INT-04 | Ø6 | 6,40 | +0,40 | vertical | P1.1A |
| P1-CTL-02 | Ø16 | 16,50 | +0,50 | horizontal | P1.1H (horizontal) |
| P1-CTL-03 | Ø22 | 22,00 | +0,00 | inclinado (32° de la vertical) | P1.1A |
| P1-INT-04 | tuerca M6 (e/c) | 10,30 | +0,30 | bolsillo abierto a la cama | P1.1A (fila hexagonal) |
<!-- /FAB:ajustes -->

---

## 8. Secuencia de fabricación y plazos estimados

| # | Paso | Depende de | Quién | Plazo estimado | Etiqueta |
|---|---|---|---|---|---|
| 0 | **Medir:** torno (volteo, entre puntos), casco real (recorte de la toma, espejo), consola | — | Gaspar / Jorge | 1 día | [SUPUESTO] |
| 1 | Pedir materia prima (MP-*), cordón O-ring, insertos, Tef-Gel; filamento PETG HDT ≥ 70 °C y secarlo | 0 | Gaspar | 1 semana (Dold/DE a DK) | [ESTIMADO: research/R08b §1] |
| 2 | Cotizar y pedir **CNC 5 ejes** (impulsor, estator) con STEP + tabla de ángulos: es el camino crítico | — | Gaspar | 3–6 semanas | [ESTIMADO: R11 §6; SLM ~72 h + torneado si se elige esa ruta] |
| 3 | Imprimir **probetas** P1.1/P1.4/P1.6/P1.7 y arrancar P1.7 (7 días en agua) | 1 | Gaspar | ~1 semana de impresora | [CALCULADO: horas de PrusaSlicer, §2.6] |
| 4 | Corte láser de chapas (S-LASER) | 0, 1 | taller | 1–2 semanas | [ESTIMADO] |
| 5 | Torno propio: eje, pasadores (+ P1.9), bujes POM, pernos, pin band, caja del sello, tapa de rodamiento; casquillos y muñones del pivote P1-REV-02 y émbolos P1-REV-04 (cuerpo, tapa, perno y pomo, §3) | 1 | Gaspar | 2–3 semanas de taller propio | [ESTIMADO] |
| 6 | Torneado de taller: carcasa, tobera fija, placa de espejo, boquilla (S-TURN-*, S-MILL-STE) | 1 | taller | 2–3 semanas | [ESTIMADO] |
| 7 | Soldadura: conducto + placa base (refrentado, prueba de estanqueidad §4), bucket (después: Ø24 H7, agujeros de traba con plantilla y buje P1-REV-03, §4), soporte de reenvío P1-REV-09, pórtico, soporte del motor, rejilla | 4 | taller + Gaspar | 1–2 semanas | [ESTIMADO] |
| 8 | Anodizado duro del lote (carcasa, estator, tobera, boquilla, poste) | 2, 6 | anodizador | 1–2 semanas | [ESTIMADO] |
| 9 | Prensar bujes (P1-REV-03: escariar Ø20,1 después) y **P1.10**; anillo de desgaste en la carcasa; tornear Ø de puntas del impulsor y **P1.12**; balanceo | 2, 5, 8 | Gaspar / taller | 1 semana | [ESTIMADO] |
| 10 | Montaje de la bomba y **P1.11** (hidrostática) | 9 | Gaspar | 2 días | [ESTIMADO] |
| 11 | Imprimir piezas del jet (tapa P1-INT-04 tras pasar P1.6; controlador y consola tras P1.1/P1.4) | 3 | Gaspar | ~1 semana de impresora | [CALCULADO: horas de PrusaSlicer, §2.6] |
| 12 | Montaje en el casco (06_ensamblaje_y_pruebas.md) | 7, 10, 11 | Jorge + Gaspar | — | — |

Camino crítico: CNC del impulsor/estator → anodizado → P1.10/P1.12 → P1.11. Con todo en paralelo, **≈ 6–9 semanas** desde el pedido [ESTIMADO: suma de los plazos más largos de la tabla].

---

## 9. Scripts y cómo regenerar

```bash
python 04_diseno/probetas/build_probetas.py          # probetas + ensayos + tablas FAB de este documento (exit ≠ 0 si falla)
python prusaslicer/validar_perfiles.py               # perfiles: formato, límites, claves y laminado (PrusaSlicer CLI)
python 04_diseno/probetas/tabla_fabricacion.py       # solo las tablas FAB (sin reconstruir probetas)
python docgen.py; python tools_check_md.py 05_fabricacion.md   # valores <!--V--> del texto
python -m pytest tests/test_probetas.py -q           # manifold, envolvente, criterios, claves críticas de los .ini
```

---

## 10. Hallazgos para el diseño (de esta pasada de fabricación)

1. **Masa y tiempo de impresión reales mayores que el manifest:** PrusaSlicer da más gramos y casi el doble de horas (tabla §2.6): el `solid_frac` de P1-CTL-02/03 y P1-ELE-01 no cuenta que 5–6 perímetros llenan paredes de 3–6 mm, y `inputs.yaml printer.print_rate_g_h` es optimista. Afecta plan y BOM de filamento, no la resistencia.
2. **Prueba de estanqueidad del conducto (S-WELD-INT): 0,3 bar de aire** es menos que la presión de cierre y el golpe de fondo (§4). Conviene sumar una hidrostática con agua a 1,5 × la presión de cierre (o justificar los 0,3 bar): decisión del grupo de la toma/BOM.
3. **P1-CTL-10 (palanca del bucket, 6061-T6 con escalón soldado):** `estructural.json` verifica la flexión **en el escalón** con el admisible del 6061-T6 sin soldar; con el de ZAT (como hace `structural_tren.py` para el 6082) el FS queda en aproximadamente la mitad. Sigue ≥ 2, pero el modelo no es coherente con la soldadura: avisar a DIRECCIÓN.
4. **Límite del torno y entre puntos:** el anillo de desgaste y el eje dependen de medidas del torno que todavía nadie tomó (§3).
5. **P1-CTL-03:** los agujeros de panel de los pulsadores están inclinados respecto de la vertical (cara a ~32°) y en Ø nominal sin holgura; P1.1A los calibra en vertical. Si el interruptor real no entra, sumar la holgura que dé P1.1 en el CAD.
6. **Bujes POM:** la holgura mínima tras 48 h (P1.10) es un [SUPUESTO] (50 % de la del CAD) a confirmar con el fabricante del buje (Vesconite/igus) si se compra en vez de tornear.
7. **Auditoría Pass 3 (semipasadores y O-ring radial) — resuelto en las probetas:** P1.9 ensaya ahora **juegos de 2 semipasadores** (uno desde cada lado) en el mismo dispositivo de corte doble, con manguito del Ø del asiento del anillo retén para que queden enrasados como en el cubo; P1.11 arma la tobera con su **O-ring radial** en la espiga y los 8 × M5, mide con galgas la luz entre bridas antes de presurizar y tapa la salida con un tapón de O-ring radial y una varilla central dimensionada desde params (la mayor métrica A4-70 que pasa por el agujero de la punta del cono de cola del estator, Ø<!--V:manifest.params.pmp_tail_hole_d:.0f-->6<!--/V--> mm; tensión y FS con la carga del tapón en la tabla §7.3; ronda 2, R2-D04) — la tobera no tiene brida de salida. La rejilla (9 pletinas, aislada con PTFE) ya figura así en S-WELD-316 de `bom.csv`.
8. **Materia prima de P1-REV-02 y P1-REV-04 (ronda 4) — resuelto:** `bom.py` dimensionaba la barra con la caja envolvente del sólido del manifest, que en P1-REV-02 incluye el tornillo M12 y en P1-REV-04 el pomo (antes, además, la contratuerca y un bloque en lugar de barras). `bom.py` acepta ahora overrides `form: bars` (varias barras por pieza) en `inputs.yaml bom.stock.overrides`: el espaciador y el cuerpo con collar + tapa salían de `MP-316-D40` y el perno de `MP-316-D18` (§3). Ronda 5: el espaciador sale de `MP-DPX-D40` (dúplex) y, desde el cierre, el cuerpo ajustado con su collar Ø32, la tapa y el pomo de `MP-316-D35`; el perno sigue en `MP-316-D18`. Desde la re-auditoría del cierre (pivote en dos piezas, MECH-1) los casquillos salen de `MP-DPX-D40` y los muñones de `MP-DPX-D22`.
9. **Ensayo P1.10:** la tabla generada (`04_diseno/probetas`) ensaya P1-PMP-07 y P1-PMP-11; falta sumar los bujes P1-REV-03 del bucket (Ø20,1 sobre el muñón Ø20 h7 del pivote), con el mismo criterio que P1-PMP-11 (≥ Ø del muñón medido + 0,05 a las 48 h [SUPUESTO: igual que P1-PMP-11]). PENDIENTES P1.7.
10. **Comentario del perfil `prusaslicer/P1_impresion_cubiertas_0.20.ini`:** dice que 5 perímetros dejan macizas «las paredes de 3,2–3,5 mm»; la caja P1-CTL-02 tiene ahora paredes de 5 mm (§2.2).
11. **Ronda 5 — compras con certificado y líneas de BOM viejas — resuelto al cerrar la ronda 5** (`inputs.yaml` corregido y `bom.csv` regenerado; auditoria.md R5-N3): el espaciador P1-REV-02 sale de `MP-DPX-D40` (dúplex 1.4462 con certificado 3.1) y los ejes y pernos de manivela de P1-REV-09 de barra 1.4401+C con certificado 3.1 (B-RELKIT). Lo que había que corregir: B-PIVM12 pedía M12 × 65, ISO 7040 y 45 N·m con Tef-Gel en la rosca → ahora M12 × 60 (`P1-REV-02.bolt_len_iso`), tuerca baja ISO 4035 A4-035 y <!--V:manifest.params.REV_bolt_T_Nm:g-->12<!--/V--> N·m con Loctite 243; B-LOCK243 daba el par del cuerpo roscado del émbolo → ahora es Loctite 243 + 641 (el cuerpo va ajustado, sin par); B-REAM16 pedía el escariador del piloto Ø16 H7 → ahora un solo Ø H7, el Ø<!--V:manifest.params.REV_sp_pilot_d:g-->24<!--/V--> (piloto y cuerpo del émbolo en las orejas y alojamiento del buje en el brazo), plantilla con espigón Ø24 h6 y sin guía de roscado; B-TAP24 pedía el macho M24×1,5 → ahora machos M20×1 y M10×1 + terraja M10×1 (el id conserva el nombre); S-LASER decía «2 balancines 5» (se fresan de placa de 12) y «montante 5» (es de 8); B-BOWDEN sumaba 0,1 m por émbolo para un eslabón de cable que ya no existe; anillos del cuerpo nuevos en B-RING24 (DIN 471-24; B-RING26 en la versión intermedia con cuerpo Ø26). `MP-316-D16`/`MP-316-D10` pedían 316L sin «+C» aunque P1-STE-02/05 se calculan con 1.4401+C (MEC-09, nota lateral): la nota del grado AISI 316 dice ahora que los pernos chicos que piden Rp0,2 ≥ 310 van en 1.4401+C con certificado 3.1 según su plano. **Error que había en las tablas generadas de §1 y §3 (FAB:procesos, FAB:torno):** esa nota nombraba P1-STE-02/05 y P1-REV-09, así que `bom.csv` asignaba **todas** las barras `MP-316-*` a esas piezas y las tablas mostraban el tubo `MP-316-TUBO-P1-PMP-02` Ø150 como su barra. La nota ya no nombra piezas y `bom.csv` asigna cada barra solo a sus piezas (P1-STE-02 → `MP-316-D16`; P1-REV-09 → `MP-5083-T6`; P1-REV-04 → `MP-316-D18` y `MP-316-D35`); las tablas FAB quedaron corregidas al regenerarlas con `tabla_fabricacion.py` (paso 6e de `run_all.py`).
12. **Re-auditoría del cierre de la ronda 5 — montaje y fabricación de la traba y del pivote (auditoria.md, «Re-auditoría del cierre de la ronda 5»):** el espaciador de una pieza del pivote **no se podía montar** (MECH-1) → pivote en dos piezas, casquillo (`MP-DPX-D40`, antes del bucket, Loctite 641 en el piloto) y muñón (`MP-DPX-D22`, después, por el buje), planos `P1-REV-02_casquillo_pivote_bucket` y `P1-REV-02_munon_pivote_bucket` (reemplazan al plano del espaciador de una pieza); el émbolo −Y pasaba a 0,26 mm del tubo de la boquilla (MECH-3) → garganta en P1-STE-01 (§3); su anillo DIN 471 no llegaba a la ranura con el orden de montaje de entonces (MECH-4) → secuencia de 06 M13; la ranura del anillo no tenía tolerancia (MECH-5) → 24,6 (+0,1/0) de la cara de apoyo del collar; la cola del perno era 2 mm larga (MECH-2) → 42 mm y control en banco de la punta; el perno y la tapa no tenían de dónde sostenerse (MECH-7) → hexágono 6 × 6 en la punta y 2 × Ø3 en la tapa; la cara interior de los brazos soldados no se controlaba (MECH-8) → ≤ 0,3 mm después de soldar (§4) y galga en T0.M6. Los pies de los lóbulos de la boquilla llevan R1,5 (FEA-3, §3).

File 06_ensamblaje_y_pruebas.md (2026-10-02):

# 06 — Ensamblaje y pruebas del waterjet

**Estado:** procedimiento de compras por etapa, cambios en el casco, montaje, aislamiento galvánico, pruebas T0–T4, FMEA, mantenimiento y bloqueos. **[NO EJECUTADO]**: no hay ninguna pieza fabricada; nada se montó ni se probó. Mandan el código y `resultados/*.json`; los números de diseño van entre marcadores `<!--V:…-->` y los regenera `docgen.py`.

Etiquetas: [VERIFICADO: fuente] · [CALCULADO] · [ESTIMADO: base] · [SUPUESTO]. IDs de pieza: `04_diseno/README.md` y `resultados/manifest.json`. Ítems de compra: columna `ID` de [`bom.csv`](bom.csv). Ensayos eléctricos T0.0–T0.20 (T0.0 = compilar el sketch y flashear el VESC a FW ≥ 6.00: sin él no hay LispBM ni perfil COSTA/ABIERTO): [`04_diseno/electronica/README.md`](04_diseno/electronica/README.md) §10. Bloqueos H-n: §8 (no confundir con los hallazgos H1–H25 de R10b).

**Reglas que valen para todo el documento**
- R1. **La estabilidad va primero.** El ensayo de escora T1.1 (R13 §5, E1) se hace con el casco SIN cortar y lastre equivalente, antes de comprar servicios o cortar el fondo. Si no pasa, no se sigue (D-04).
- R2. **El sello mecánico nunca gira en seco.** Con el bote fuera del agua el eje se gira solo a mano y despacio. El motor gira solo con la estrella del acople sacada (T0) [ESTIMADO: R10a §0.2, §8.3].
- R3. **Tef-Gel en todo A4/316 que toque aluminio**, más arandela aislante de nylon (B-TEFGEL, B-ISOW) (§4). Excepciones: la rosca del M12 de los pivotes del bucket, con Loctite 243 (par calculado con fijador, R7), y los ajustes Ø<!--V:manifest.params.REV_lock_bore_d:g-->24<!--/V--> H7/h6 del cuerpo de los émbolos y del piloto de los casquillos del pivote en las orejas, con Loctite 641 (retenedor, sin par: llena el juego; M13 y §4).
- R4. **Marca de pintura** cruzando cabeza y pieza en toda unión apretada: si la marca está corrida, la unión está floja.
- R5. **Sistema eléctrico flotante:** BAT− no toca el casco; aislación > 1 MΩ (T0.1) [VERIFICADO: R06 §5.1, ISO 13297 4.1].
- R6. **Nunca trabajar en la rejilla, la chimenea o la popa con el sistema armado:** cordón afuera y S1 en OFF [VERIFICADO: R10a §0.1].
- R7. **Pares de apriete.** Calculados en el repositorio: tuercas M8 del pórtico <!--V:manifest.params.drv_nut_torque_Nm:.0f-->10<!--/V--> N·m con Tef-Gel (F_v <!--V:manifest.params.drv_nut_Fpre_N:.0f-->6944<!--/V--> N; lo limita el asiento avellanado en la placa base de 5083, P1-DRV-03/P1-INT-02, estructural.json), M6 de la brida del conducto en rosca ciega de Al <!--V:manifest.params.toma_m6_torque_Nm:.1f-->2.4<!--/V--> N·m + Loctite 243 (barrido del filete, P1-INT-02), tornillos M12 A4-80 de los pivotes del bucket <!--V:manifest.params.REV_bolt_T_Nm:g-->12<!--/V--> N·m (**par bajo a propósito**: el tornillo solo retiene; el corte y el momento los lleva el piloto del casquillo en la oreja) con **Loctite 243** en la rosca, no Tef-Gel (precarga <!--V:est.loads.structural_direccion.bolt_pre_min_N:.0f-->3571<!--/V-->–<!--V:est.loads.structural_direccion.bolt_pre_max_N:.0f-->6667<!--/V--> N con K <!--V:manifest.params.REV_bolt_K.0:g-->0.15<!--/V-->–<!--V:manifest.params.REV_bolt_K.1:g-->0.28<!--/V--> [ESTIMADO]; P1-REV-02, `estructural.json`; re-auditoría ronda 5, MEC-01/02). El cuerpo de los émbolos P1-REV-04 ya no lleva par: va ajustado Ø<!--V:manifest.params.REV_lock_bore_d:g-->24<!--/V--> H7/h6 con Loctite 641, sin rosca ni precarga (cierre de la ronda 5, R5-N1; hasta entonces era un cuerpo M24×1,5 apretado a 110 N·m). **No pasarse del par de los pivotes.** Para el resto (M3–M8 A4-70, M5 del soporte del desbloqueo, KM4, prisioneros) usar la tabla del proveedor de la tornillería y la del fabricante del rodamiento; **no están calculados** (bloqueo H-6). Nunca usar el par de tabla de acero en una rosca hecha en aluminio.

---

## 1. Compras y fabricación por etapa

La lista completa, con proveedor, precio, etiqueta y especificación mínima, está en [`bom.csv`](bom.csv). Total del sistema <!--V:bom.total_eur:.0f-->11837<!--/V--> € ≈ <!--V:bom.total_dkk:.0f-->88489<!--/V--> DKK; con los cambios de casco y el equipo de operación, <!--V:bom.total_with_hull_and_gear_eur:.0f-->12556<!--/V--> € [CALCULADO: `bom.py`]. Regla: **no se compra nada caro antes de cerrar P0** (PENDIENTES_GASPAR).

| Etapa | Condición para empezar | IDs de `bom.csv` | Monto | Nota |
|---|---|---|---|---|
| E0 — Medir y decidir | Ninguna | Nada (cinta, nivel, balanza, lastre) | — | PENDIENTES P0: medidas, estabilidad, cotizaciones, consulta legal |
| E1 — Casco y seguridad del bote (Jorge) | T1.1 (E1) aprobado con el casco tal cual o ya modificado; casco medido | H-CUT-BOT, H-CUT-TR, H-HOLES, H-FLOORS, H-WELD, H-SIKA, H-PRIMER, H-BATT, H-FOAMBAY; B-FOAM, B-BILGE, B-ALARM, B-BILGE-HOSE, B-12V | Casco: <!--V:bom.hull_changes_eur:.0f-->504<!--/V--> € | Los cortes se replantean sobre el casco medido (§2) |
| E2 — Equipo de operación | Antes de la primera prueba en el agua (T1) | B-PFD, B-CORD, B-PADDLE, B-ANCHOR, B-LIGHT, B-BAILER | <!--V:bom.operation_gear_eur:.0f-->215<!--/V--> € | Va también con la JT132 (opción B) |
| E3 — Núcleo eléctrico | Respuesta de Maytech (potencia continua, pares de polos) y `run_all.py` en verde | B-MOT, B-ESC, B-BAT, B-CHG | Núcleo: <!--V:bom.core_eur:.0f-->1952<!--/V--> € | Sirve para A y para B (D-05). Medir las baterías recibidas antes de comprar B-BOX |
| E4 — Potencia, seguridad eléctrica y mando | E3 recibido | B-BOX, B-FUSE, B-FUSEH, B-FUSE-BR, B-FUSEH-BR, B-SW, B-BUS, B-CAB-*, B-TERM*, B-PHCON, B-LUG10, B-SHRINK*, B-ANDERSON, B-CHGFUSE, B-GLAND32, B-RPRE, B-CONT, B-HOLD, B-KILL, B-ESTOP, B-CFUSE, B-KCONN, B-MCU, B-DCDC, B-PCB, B-HALL, B-MAG, B-SIGNAL, B-ENCL, B-WIRE, B-CRIMP | — | B-CONT = TE EV200AAANA (bobina 9–36 V con economizador, a 12 V desde B-12V RSD-60L-12): confirmar stock y precio al pedir |
| E5 — Servicios de fabricación (solo opción A) | AWT no confirma las 4 condiciones de 03 §3, o la JT132 no entra en el casco | S-CNC-IMP, S-CNC-STAT, S-TURN-HSG, S-TURN-NOZ, S-TURN-TP, S-MILL-STE, S-LASER, S-WELD-INT, S-WELD-AL, S-WELD-316, S-ANOD; materia prima MP-* (con MP-5083-AROS); herramienta de la traba B-REAM16, B-TAP24 | Servicios <!--V:bom.services_eur:.0f-->4015<!--/V--> € + materia prima <!--V:bom.raw_material_eur:.0f-->1326<!--/V--> € | Con la JT132 queda solo la placa de adaptación de la toma, el pórtico y el soporte del motor (03 §4) |
| E6 — Tren, sellado y corrosión | E5 encargado (o JT132 comprada) | B-SEAL, B-BRG, B-KM4, B-CPL, B-KEY, B-CIRC, B-NUT16, B-LOCTITE, B-HW, B-STUD, B-INS, B-ORING, B-GREASE, B-GASKET, B-GLAND16, B-GLAND20, B-TEFGEL, B-ISOW, B-PTFE, B-ANODE, B-TAP, B-DIAL | — | Comprar con el eje: el sello y los rodamientos se prueban en el eje terminado |
| E7 — Refrigeración y mandos | Consola de Jorge medida | B-HOSE, B-BARB, B-HCLAMP, B-STRAIN, B-COOL-THRU; B-HELM, B-M66, B-WHEEL, B-MACH5, B-ROD5, B-ROT8, B-PIVM12, B-SPRING, B-RING24, B-LOCK243, B-RELKIT, B-BOWDEN, B-GLINS, B-KNOB | — | Largo del M66, del Mach5 y de los dos Bowden medidos en el bote. Resortes, émbolos y Bowden: control de recepción (PENDIENTES P1.8–P1.9) |
| E8 — Impresión en PETG | Perfiles y probetas de 05 aprobados | B-PETG → P1-CTL-02, P1-CTL-03, P1-ELE-01, P1-ELE-02, P1-INT-04 | <!--V:manifest.totals.printed_mass_g:.0f-->1051<!--/V--> g, <!--V:manifest.totals.printed_hours:.0f-->58<!--/V--> h | Piezas secas o de baja carga (D-19) |
| E9 — Repuestos | Con E6 | R-SEAL, R-ORING, R-SPIDER, R-FUSE, R-PIN, R-BUSH | — | R-PIN: <!--V:manifest.params.pmp_pin_spares_sets:.0f-->3<!--/V--> juegos de 2 semipasadores de corte (H-12) |

---

## 2. Cambios en el casco que hace Jorge

Todas las cotas salen del CAD (`resultados/manifest.json → params`) con el casco **leído del plano** (D-02, [ESTIMADO]). Antes de cortar: casco medido (PENDIENTES P0.1), `inputs.yaml → boat.*` actualizado, `python run_all.py` en verde y **replanteo sobre el casco real** con plantilla de cartón o MDF. Origen: cara exterior del espejo, crujía, quilla (x hacia proa, z hacia arriba).

| # | Cambio | Cotas (CAD) | Verificar antes de seguir |
|---|---|---|---|
| C1 | **Recorte del fondo para la placa base P1-INT-02** (H-CUT-BOT) | La placa va de x = <!--V:manifest.params.toma_plate_x0:.0f-->286<!--/V--> a <!--V:manifest.params.toma_plate_x1:.0f-->801<!--/V--> mm, semiancho <!--V:manifest.params.toma_plate_y:.0f-->150<!--/V--> mm, en crujía; el recorte es la placa menos el ala de <!--V:manifest.params.toma_rim_w:.0f-->25<!--/V--> mm por lado, con <!--V:manifest.params.toma_seal_gap:.1f-->0.5<!--/V--> mm de luz para el Sikaflex. Abertura hidráulica <!--V:manifest.params.L_open:.0f-->380<!--/V--> × <!--V:manifest.params.W_open:.0f-->158<!--/V--> mm entre el labio (x = <!--V:manifest.params.x_lip:.0f-->386<!--/V-->) y la tangencia de la rampa (x = <!--V:manifest.params.x_tan:.0f-->766<!--/V-->). Fondo de <!--V:manifest.params.bottom_t:.0f-->4<!--/V--> mm [SUPUESTO: medir] | Zona plana, sin quilla, tracas ni remaches en la abertura y ≥ 0,5 m limpio a proa de la tangencia [VERIFICADO: R10a §7, §8.2]. Escalón placa ↔ fondo ≤ 1 mm (P1-INT-02). **Espesor real del fondo** (con cualquier sobreplaca): con el supuesto la tobera fija y la carcasa quedan a pocos milímetros del fondo interior; si supera 6 mm, subir `waterjet.axis_height_m` lo mismo, correr `run_all.py` (`verify_parts.py` falla si no) y revisar que el eje siga bajo la flotación (`sizing.priming.axis_below_wl_m`) [auditoria.md W-16] |
| C2 | **Agujeros del ala** (H-HOLES) | M<!--V:manifest.params.toma_hull_bolt:.0f-->6<!--/V--> ISO 10642 A4-70 avellanados desde afuera, paso <!--V:manifest.params.toma_hull_pitch:.0f-->70<!--/V--> mm, tuerca autofrenante A4 adentro. Taladrar con la placa presentada como plantilla | Avellanado: cabeza enrasada con el fondo |
| C3 | **Agujero del espejo** (H-CUT-TR) | Ø<!--V:manifest.params.transom_hole_d:.1f-->166.0<!--/V--> mm, centro en crujía a z = <!--V:manifest.params.z_noz:.0f-->92<!--/V--> mm sobre la quilla (eje de la tobera). Espejo de <!--V:manifest.params.transom_t:.0f-->6<!--/V--> mm [SUPUESTO: medir]. Tolerancia **Ø +1/0** y **concentricidad ≤ 0,5 mm** con el eje del jet (o cortarlo coaxial al eje inclinado <!--V:manifest.params.alpha:.0f-->5<!--/V-->°): la brida de la tobera tiene que pasar por popa en el servicio con el eje inclinado (luz ≈ 1,6 mm por lado, `service_paths`, auditoría R2-D03). Más los 6 × M6 de la placa de espejo P1-PMP-09 (taladrar con la placa como plantilla) | El agujero queda concéntrico con el eje del conducto: verificar con el conducto presentado y un hilo tenso por el eje antes de cortar |
| C4 | **Pasos del espejo, sobre la flotación** (H-HOLES) | Pasacasco del testigo de refrigeración P1-ELE-03 (Ø17); salida de achique (B-BILGE-HOSE); pasamuros M66 P1-CTL-04 (M20 × 1,5) y 2 prensaestopas M16 (Mach5 y Bowden) en la placa interior P1-CTL-01 (6 × M6); 2 × M6 del tope de dirección P1-STE-08 | Todo por encima de la flotación medida (T1.2): la flotación de cálculo está a <!--V:sizing.hydrostatics.draft_m:.3f-->0.287<!--/V--> m de la quilla [CALCULADO] |
| C5 | **Varengas y refuerzos** (H-FLOORS, H-WELD) | Al 5083 6 mm a ambos lados del recorte y bajo el pórtico (x ≈ <!--V:manifest.params.brg_bracket_x0:.0f-->532<!--/V-->–<!--V:manifest.params.brg_bracket_x1:.0f-->682<!--/V-->) y el soporte del motor (x ≈ <!--V:manifest.params.mot_x0:.0f-->682<!--/V-->–<!--V:manifest.params.mot_x1:.0f-->797<!--/V-->); refuerzo del borde del recorte. Los pies del motor P1-MOT-02 van con 4 × M<!--V:manifest.params.mot_foot_bolt:.0f-->8<!--/V--> a las varengas a través del piso | El empuje a punto fijo, hasta <!--V:sizing.mech.Fa_max_N:.0f-->765<!--/V--> N [CALCULADO], va del pórtico a la placa base y de los bulones del ala al casco: las varengas le dan rigidez al borde del recorte. Soldadura con cordones intermitentes, sin recalentar el fondo (H-WELD). Dimensionarlas con el casco medido |
| C6 | **Piso en la zona del motor** | Piso a z = <!--V:manifest.params.floor_z:.0f-->75<!--/V--> mm sobre la quilla en el CAD; luz motor ↔ piso <!--V:manifest.params.mot_clear_floor:.0f-->16<!--/V--> mm [CALCULADO] | Si el piso real está más alto, cambia el soporte del motor: medir antes de pedir P1-MOT-02 |
| C7 | **Flotación fija ~100 L** (B-FOAM, H-FOAMBAY) | Espuma de celda cerrada en compartimentos bajo el asiento y en proa, repartida a ambas bandas, **fuera de la sentina** [ESTIMADO: R10b H5, 1,5 × peso neto sumergido] | E2/E3 (T1.4–T1.5): flota inundado con escora ≤ 10° [VERIFICADO: 33 CFR 183.225]. La espuma PU pierde flotación con inmersión continua: revisable [VERIFICADO: R11 §10.12] |
| C8 | **Achique** (B-BILGE, B-ALARM, B-12V, B-BILGE-HOSE) | Bomba automática en el punto más bajo de la sentina (a proa de la toma), alarma de nivel alto, 12 V desde un DC-DC aislado **aguas arriba de S1/K1** con fusible F4 | Funciona con el kill tirado y S1 en OFF (T0.M8) |
| C9 | **Bancada de baterías** (H-BATT) | Caja estanca B-BOX con las 2 baterías (≈ 40 kg) sobre calzos, por encima del nivel de sentina, 2 correas ≥ 4 × peso | ISO 13297 8.1: batería en lugar seco sobre el agua de sentina [VERIFICADO: R06 §5.1] |
| C10 | **Cockpit** (si E1 lo exige y para la clasificación legal) | Asiento bajo la borda, brazola ≥ 250 mm, volante, palancas y respaldo; nada de montura ni manillar [ESTIMADO: R13 §1.4, §9] | Es lo que sostiene que no es "vandscooter" (D-20). Si E1 falla: manga en la flotación ≥ 0,9 m o flotadores laterales (D-04) |

La chimenea de inspección termina a z = <!--V:manifest.params.toma_chim_top:.0f-->350<!--/V--> mm: su tapa tiene que quedar ≥ 60 mm sobre la flotación medida [visor REVISAR P1-INT-04; R10a §0.3]. Si con el casco medido no queda, alargar la chimenea antes de soldar.

---

## 3. Secuencia de montaje

Prerrequisitos: T1.1 aprobado (R1); cambios de casco C1–C10 hechos; piezas recibidas e inspeccionadas contra sus planos (`04_diseno/planos/`); ensayos de taller de 05 §7 aprobados, en particular la **prueba de estanqueidad del conducto soldado** (aire 0,3 bar + jabón, S-WELD-INT) y la **prueba hidrostática de la toma y la bomba a 0,3 MPa** [ESTIMADO: R12 §7.2; presión de diseño <!--V:est.loads.structural_bomba.loads_used.p_design_Pa:.0f-->200000<!--/V--> Pa]. Las piezas tienen el orden de montaje verificado en el CAD (checks de P1-DRV-01: cada pieza pasa por los Ø de lo ya montado; `params_tren.py`).

**Importante — qué pasa por el agujero del espejo** (Ø<!--V:manifest.params.transom_hole_d:.1f-->166.0<!--/V-->): la brida de la toma de la carcasa (Ø<!--V:manifest.params.pump_flange_od:.0f-->193<!--/V-->) **no** pasa: la carcasa se monta desde adentro del casco y no se vuelve a sacar salvo para cambiar el anillo de desgaste (eso sí obliga a sacar el eje hacia proa). La tobera fija (brida Ø<!--V:manifest.params.pmp_f2_od:.1f-->161.1<!--/V-->), el estator, el impulsor y los semipasadores **sí** pasan: se montan y se sacan **por popa** sin tocar el tren (auditoría Pass 3 H1; `verify_parts.py` V7 y los checks «camino de extracción» de P1-PMP-08 lo comprueban). La placa de espejo se pone desde afuera.

| Paso | Qué | Cómo (uniones y pares) | Verificar antes del paso siguiente |
|---|---|---|---|
| M1 | **Toma: placa base + conducto** (P1-INT-01/02, subconjunto soldado por el taller) | Presentar en seco desde adentro: el ala apoya sobre el casco y el cuerpo llena el recorte. Limpiar, Sika Aktivator + Primer (H-PRIMER), cama de Sikaflex-291i de 0,5–1 mm en el ala y en la luz (H-SIKA). Bulones M6 del ala (C2) con Tef-Gel. En el mismo paso, los 4 tornillos ISO 10642 M8 × 35 A4-70 del pórtico (B-STUD) desde afuera, cabeza en Sikaflex, tuerca provisoria. Curado según la ficha de Sika (R05 S36) antes de cargar | Escalón ≤ 1 mm en todo el perímetro; cordón de Sikaflex continuo afuera y adentro; los 4 espárragos perpendiculares a la placa (escuadra) |
| M2 | **Rejilla y tapa de inspección** (P1-INT-03, P1-INT-04) | Rejilla desde afuera, 4 × M5 A4 con Tef-Gel. Tapa con O-ring y grasa de silicona (B-GREASE), 4 × M6 con arandela ancha; tornillo de purga con arandela de estanqueidad | Barras enrasadas, escalón ≤ 2 mm y sin rebabas [VERIFICADO: R10a §8.6]; luz entre barras <!--V:manifest.params.toma_bar_gap:.1f-->12.2<!--/V--> mm (ver H-11 sobre dedos) |
| M3 | **Carcasa con impulsor** (P1-PMP-01 con P1-PMP-02 prensado y torneado por el taller; P1-PMP-03) | Impulsor adentro del anillo de desgaste (queda suelto hasta que llegue el eje). O-ring de cara en la carcasa (grasa de silicona). **Espigón de centraje Ø<!--V:manifest.params.pmp_f1_spigot_d:.0f-->140<!--/V--> h6 de la carcasa en el rebaje H7 del conducto** (P1-INT-01, mecanizado después de soldar coaxial con el buje del sello). Carcasa contra la brida del conducto con <!--V:manifest.params.pump_flange_n:.0f-->8<!--/V--> × M<!--V:manifest.params.pump_flange_bolt:.0f-->6<!--/V--> A4, Tef-Gel, tuercas A4 del lado del conducto, apriete en cruz | Las caras de brida apoyan en todo el perímetro (galga 0,05 no entra); puerto de refrigeración <!--V:manifest.params.pmp_cool_thread:-->G1/8<!--/V--> arriba; la carcasa no toca el espejo |
| M4 | **Eje con sello, en banco** (P1-DRV-01, P1-DRV-02, P1-DRV-07) | Asiento fijo del sello prensado en la caja (copa de NBR mojada con agua, sin grasa en las caras). Desde la **punta de popa** del eje: caja del sello hasta el collar y cabeza rotante hasta su anillo DIN 471 de respaldo. Después, anillo DIN 471 de empuje + arandela 316 en la ranura delantera del impulsor (B-CIRC) | Nada pasa por el collar Ø26; caras del sello limpias (alcohol isopropílico, sin tocarlas con los dedos); fuelle sin torcer |
| M5 | **Eje con sello, desde proa** | El subconjunto entra por proa, punta de popa primero, por el buje del sello de la toma (Ø<!--V:manifest.params.seal_spigot_d:.0f-->42<!--/V--> H8), el tubo del conducto y el agujero del impulsor. Espigón de la caja en el buje con Tef-Gel; 4 × M6 A4 de la caja con Tef-Gel y arandela aislante | El impulsor apoya contra la arandela y el DIN 471 de empuje; la linterna del sello queda con las ventanas a la vista y la salida G1/8 abajo |
| M6 | **Pórtico deslizando sobre el eje** (P1-DRV-03) | El alojamiento es cerrado: **no baja vertical**. Sacar las tuercas provisorias. Apoyar el pórtico <!--V:manifest.params.drv_brg_travel:.0f-->66<!--/V--> mm más a proa (a lo largo del eje), con el alojamiento delante de la punta de proa del eje y los espárragos de proa ya dentro de las **ranuras abiertas hacia popa** de las zapatas; deslizarlo hacia popa sobre el eje (el resalte Ø<!--V:manifest.params.drv_brg_shoulder_hole:.1f-->32.5<!--/V--> pasa sobre el Ø20) hasta el fondo de las ranuras. Arandela ancha ISO 7093 + tuerca ISO 4032 A4 **a mano** | Zapatas apoyadas planas sobre la placa base (galga 0,05 mm no entra); los 4 espárragos en el fondo/centro de las ranuras |
| M7 | **Rodamientos, KM4, tapa y alineación** (P1-DRV-04/05/06) | Par **7204 BECBP** (apareable universal) **en O**, prensados a la vez en el alojamiento y en el muñón **desde proa** contra el collar (tubo de montaje sobre los dos aros). MB4 + KM4 con llave de gancho (aprieta los aros interiores contra el collar; los exteriores quedan entre el resalte y la tapa: el juego del par lo da el apareo CB) y doblar un diente de la MB4 en la ranura. Tapa P1-DRV-06 con 4 × M<!--V:manifest.params.drv_cover_bolt:.0f-->5<!--/V--> A4 y Tef-Gel; grasa + anillo V del lado del acople. **Alineación con el propio eje como mandril** (R2-D07): estator presentado en la carcasa con su buje de agua P1-PMP-07; el eje queda libre en el buje (girarlo a mano) y se mide con galgas la luz eje ↔ buje arriba, abajo y ±Y, moviendo el pórtico (±0,5 en las ranuras) hasta igualarla; apretar las tuercas M8 a <!--V:manifest.params.drv_nut_torque_Nm:.0f-->10<!--/V--> N·m con Tef-Gel; taladrar y escariar con TOPE 2 pasadores **ISO 8735 Ø6 × 16 A4 (rosca interior M4)** por zapata en las posiciones del plano P1-DRV-03 (pasantes en la zapata, **ciegos 6 mm en la placa base**: quedan 4 mm de fondo mojado; toman el corte en x que la ranura no toma) y sacar el estator. En servicio, los pasadores se extraen con un tornillo M4 para poder deslizar el pórtico | **T0.M1** giro libre a mano y **T0.M3** juego axial. Marca de pintura en las 4 tuercas |
| M8 | **Semipasadores, retén, estator y tobera** (P1-PMP-04 a 08), **por popa** a través del agujero del espejo (o desde adentro, por popa de la carcasa) | 2 semipasadores Al 6061 Ø<!--V:sizing.mech.shear_pin.d_mm:.1f-->3.5<!--/V--> (uno desde cada lado, se tocan en el centro del eje); anillo retén P1-PMP-04 deslizado (Loctite 641) y 2 × M3 avellanados; arandela + DIN 471 de retención de popa. Estator con el buje de agua ya prensado (H7/s6, desde proa, en banco) deslizado en la carcasa sobre el muñón; 2 × M5 radiales ±Y roscados en la carcasa con **arandela bonded** bajo la cabeza (la punta entra en el agujero liso de la camisa); agujero de refrigeración alineado con el puerto. Tobera fija con O-ring radial en la espiga (grasa de silicona) y <!--V:manifest.params.pmp_f2_n:.0f-->8<!--/V--> × M5 × 20 A4-70 ISO 4762 con Tef-Gel desde popa, roscados en la carcasa (7,75 mm de rosca: un M5 × 25 toca fondo) | Luz entre las caras de las bridas carcasa ↔ tobera <!--V:manifest.params.pmp_stack_gap:.2f-->0.25<!--/V--> ± 0,05 con galgas (si es 0, la espiga no aprieta la camisa: rectificar). **T0.M2** holgura de punta con galgas y **T0.M1** otra vez |
| M9 | **Placa de espejo desde popa** (P1-PMP-09, P1-PMP-10, P1-PMP-11) | Junta NBR + **masilla butílica no adhesiva** en ambas caras (NO Sikaflex: la placa se saca en cada cambio de semipasadores, auditoría R2-D05). O-ring radial con grasa de silicona en el resalte de la tobera; la placa desliza el cuello sobre el resalte. 6 × M6 A4 a través del espejo con Tef-Gel, **arandelas bonded de sellado (USIT M6)** bajo cabeza y tuerca, arandelas aislantes y arandelas grandes o contraplaca adentro. Bujes POM de pivote prensados | La bomba sigue apoyada solo en la brida de la toma (centrada por el espigón): aflojar y volver a apretar la placa no mueve el eje (comparador en el cubo del acople, sin cambio) |
| M10 | **Acople** (P1-DRV-08) | Cubo del lado del eje refrentado a su largo de montaje, chaveta 6 × 6 A4 (B-KEY) y prisionero con Loctite 243 (lejos de todo PETG). Cubo del lado del motor **de acero** (Rotex «St», no Al-D) en el eje Ø15 del motor con su chaveta **y Loctite 648** en el asiento (la chaveta del motor da FS 1,74 a T_max: hallazgo abierto C13/H13, `estructural.json`); medir el largo del chavetero del motor recibido. Estrella T-PUR 92 ShA | Chavetas sin juego lateral; prisioneros con marca |
| M11 | **Motor** (P1-MOT-01 sobre P1-MOT-02) | Soporte a la cara del motor con <!--V:manifest.params.mot.mount_n:.0f-->4<!--/V--> × M<!--V:manifest.params.mot.mount_bolt:.0f-->6<!--/V--> (medir el motor recibido). Pies a las varengas con 4 × M8 a través del piso, con Tef-Gel. Separación entre cubos = <!--V:manifest.params.drv_coupling.s:.1f-->2.0<!--/V--> mm (juego axial: el motor no recibe empuje) | **T0.M4** alineación del acople; T0.M1 con el motor acoplado |
| M12 | **Refrigeración** (B-BARB, B-STRAIN, B-HOSE, B-HCLAMP, P1-ELE-03) | Espiga 316 en el puerto de la carcasa → filtro en línea → manguera Ø6 × 8 → caja de agua del controlador → camisa del motor → pasacasco testigo del espejo (sobre la flotación, a la vista). Abrazaderas A4 en cada espiga. Manguera de la linterna del sello (G1/8 abajo) a la sentina, visible | **T0.M7** con agua de red: sin fugas y sale por el testigo |
| M13 | **Boquilla, bucket y cables** (P1-STE-*, P1-REV-*, P1-CTL-01/04/05) | Boquilla entre las orejas de la placa de espejo con 3 arandelas POM; perno superior P1-STE-02 y espárrago inferior P1-STE-05 roscados M6 con Loctite 243. Brida del yugo 4 × M8 A4 con Tef-Gel, poste, brazo, biela M8 con contratuercas. Tope de dirección P1-STE-08 al espejo (2 × M6). **Émbolos P1-REV-04** (cuerpo ajustado desde el cierre de la ronda 5, sin rosca ni par; R5-N1), uno por oreja ±Y, **antes del bucket y del soporte P1-REV-09** (el collar queda en la luz entre el lóbulo y el brazo): armar cada émbolo en el banco: guía Ø16 H8 del cuerpo engrasada con pasta antiengrane (perno 316 en guía 316: §4, CALC-3), perno con su resorte en el cuerpo, tapa M20×1 con **Loctite 243** apretada con llave de gancho en sus 2 × Ø3 y pomo roscado **a fondo** en la cola con Loctite 243 (B-LOCK243) **sosteniendo el perno con una llave Allen de 6 en el hexágono de la punta** (re-auditoría del cierre de la ronda 5, MECH-7); **control en banco** (MECH-2): con el pomo apoyado en la tapa, la punta del perno queda a 10,0 ± 0,2 de la cara exterior del collar [CALCULADO: plano P1-REV-04_embolo_perno]; si no, el pomo no llegó al fondo o la cola está larga: no montar. Ø<!--V:manifest.params.REV_lock_bore_d:g-->24<!--/V--> h6 del cuerpo y Ø<!--V:manifest.params.REV_lock_bore_d:g-->24<!--/V--> H7 de la oreja limpios y desengrasados, **sin Tef-Gel**; **Loctite 641** (B-LOCK243) en el tramo del cuerpo que queda en el lóbulo (los <!--V:manifest.params.STE_lock_t:g-->23.5<!--/V--> mm junto al collar); meter el cuerpo armado **desde afuera** de la oreja (el pomo Ø23 pasa por el Ø<!--V:manifest.params.REV_lock_bore_d:g-->24<!--/V--> H7 con 1 mm de holgura diametral y el cuerpo, de un solo Ø, entra ajustado [CALCULADO: checks «pomo pasa por el agujero de la oreja al montar desde afuera» y «cuerpo de un solo Ø» de P1-REV-04]) **dejando ≈ 20 mm afuera** [SUPUESTO: re-auditoría del cierre de la ronda 5, MECH-4]. **Arandela y anillo por dentro** (MECH-4): junto al tubo de la boquilla no hay luz para correr el anillo abierto a lo largo del cuerpo (en el émbolo −Y quedan 2 mm hasta la garganta del tubo [CALCULADO: check de P1-REV-04] y la sección del anillo abierto sobresale más), así que, con el cuerpo así, pasar por su extremo interior la arandela 316 Ø24,2 × Ø32 × 0,8 y el anillo **DIN 471-24 A4** (B-RING24) abierto con la pinza, **sostener el anillo abierto con la pinza** mientras otra persona empuja el cuerpo (el Loctite 641 ya puesto) hasta que el **collar exterior Ø32** [CALCULADO: `piezas/_release.PLG_COLLAR_D`] apoye en la cara exterior del lóbulo de la traba, **anodizada** (§4; queda 1 mm de luz al brazo del bucket [CALCULADO: check de P1-REV-04]), y soltar el anillo en su ranura, contra la arandela y la cara interior del lóbulo engrosado; el émbolo +Y se puede montar igual. No hay llave dinamométrica ni marca de pintura cuerpo–oreja: el ajuste con Loctite 641, el collar y el anillo fijan el cuerpo. Con el collar apoyado, una galga de 0,05 mm no entra entre collar y lóbulo [SUPUESTO: cara del collar a escuadra ≤ 0,02, plano P1-REV-04_embolo_cuerpo]; dejar curar el Loctite 641 según su ficha antes de cargar la traba [SUPUESTO: práctica]. **Casquillos del pivote P1-REV-02** (pivote en dos piezas de dúplex 1.4462 desde la re-auditoría del cierre de la ronda 5, MECH-1), uno por oreja, **también antes del bucket**, desde afuera: piloto Ø<!--V:manifest.params.REV_sp_pilot_d:g-->24<!--/V--> h6 y Ø<!--V:manifest.params.REV_sp_pilot_d:g-->24<!--/V--> H7 de la oreja limpios y desengrasados, **Loctite 641** (B-LOCK243) en el piloto (llena el juego: el piloto es el camino de carga del pivote, FEA-4) y Tef-Gel solo en la cara de apoyo de la brida; el piloto entra en el H7 (a mano o con golpes suaves de maza de goma) hasta que la brida Ø<!--V:manifest.params.REV_sp_fl_d:g-->36<!--/V--> apoye en la cara exterior **anodizada** de la oreja (§4); su fondo queda enrasado con la cara interior del lóbulo del pivote [CALCULADO: check «fondo del casquillo enrasado con la cara interior del lóbulo» de P1-REV-02]. Bucket con bujes POM P1-REV-03 ya prensados y escariados a Ø20,1 (05 §4), presentado con los dos pernos de traba retraídos (tirar de cada pomo con la mano: el perno entra en el cuerpo y libra el brazo) y bajado sobre las orejas: las bridas de sus bujes pasan junto a las de los casquillos con 0,5 mm de luz [CALCULADO: check de P1-REV-03]. **Muñones P1-REV-02**, uno por lado: desde afuera, por el buje, con Tef-Gel (dúplex en el casquillo y en el buje; Tef-Gel **no en la rosca**), hasta el fondo del casquillo; tornillo ISO 4017 M12 × 60 A4-80 (`P1-REV-02.bolt_len_iso`) con arandela ISO 7089 bajo la cabeza, sobre el extremo del muñón; por dentro, arandela ancha ISO 7093 Ø<!--V:manifest.params.REV_washer_in.0:g-->37<!--/V--> × <!--V:manifest.params.REV_washer_in.1:g-->3<!--/V--> sobre el fondo del casquillo y la cara interior del lóbulo (enrasados: sin puente, CALC-4) y tuerca **baja ISO 4035 M12 A4-035** (m <!--V:manifest.params.REV_nut_h:g-->6<!--/V--> mm, no autoblocante; con ella el M12 × 60 alcanza para el lóbulo del pivote; B-PIVM12, PENDIENTES P1.11); **Loctite 243** (B-LOCK243) en la rosca y **par <!--V:manifest.params.REV_bolt_T_Nm:g-->12<!--/V--> N·m** con llave dinamométrica (precarga <!--V:est.loads.structural_direccion.bolt_pre_min_N:.0f-->3571<!--/V-->–<!--V:est.loads.structural_direccion.bolt_pre_max_N:.0f-->6667<!--/V--> N por cabeza → muñón → fondo del casquillo ← arandela, P1-REV-02; más par hace fluir la brida y el muñón, MEC-01); el bucket gira a mano sin juego axial visible. Marca de pintura tuerca–tornillo–oreja. Soporte Mach5 P1-REV-05, varilla y perno P1-REV-06 (Loctite 243). **Desbloqueo** (re-auditoría ronda 5, DES-04/07/08): con el **bucket ARRIBA** (el soporte entra deslizando desde popa: no baja vertical sobre el pad), presentar el soporte de reenvío P1-REV-09 con los balancines ya montados (casquillos poliméricos engrasados en los cubos, arandela PTFE entre alma y montante, anillo DIN 6799 en cada eje) desde popa ≥ 30 mm y deslizarlo hacia proa hasta apoyar la base de cara en el pad de la boquilla; 2 × ISO 4762 M5 × 12 A4-70 con Tef-Gel y arandela de nylon (B-RELKIT; sacarlo da acceso a los anillos DIN 471 de los émbolos y a las tuercas de los pivotes). **Eslabones rígidos** (uno por émbolo): roscar el vástago M4 del ojo, por el agujero Ø4,5 del fondo del pomo, en la rosca M4 axial de la cola del perno del émbolo con Loctite 243, ranura del ojo vertical, y enganchar el ojo en el perno de manivela de su balancín con el clip DIN 6799. **Orden de ajuste:** 1) bucket trabado, pomo apoyado en su tapa y Bowden **flojo**: ajustar el largo del eslabón por medias vueltas (±2 mm de rango) hasta que el perno de manivela quede a la altura del eje del émbolo (plano P1-REV-09_eslabon); 2) recién después, el regulador M6 del Bowden. Cada Bowden (B-BOWDEN) con su barril en el brazo de salida del balancín, regulador M6 en la pestaña de P1-REV-09, vaina por el recorrido del plano P1-REV-10_recorrido_vaina (curva ≥ R30) y bucle libre hasta la placa del espejo. Regular los dos reguladores para que, en reposo, cada pomo apoye en su tapa con el cable **apenas flojo** (si el cable queda tenso, el perno no entra; mismo criterio que el plano P1-REV-10). Pasamuros M66 y prensaestopas en la placa P1-CTL-01 (Sikaflex afuera). Mach5 y Bowden con un bucle libre hasta la boquilla | **T0.M6**: la dirección para en el tope (±<!--V:manifest.params.STE_stop_deg:.1f-->26.5<!--/V-->°) antes de que la boquilla toque la tobera; el bucket arriba no toca el chorro; las dos trabas entran arriba y abajo y el gatillo las saca: **T0.M6b** [CALCULADO: `verify.json` sin interferencias en δ ±<!--V:manifest.params.steer_max:.0f-->25<!--/V-->° y bucket arriba/abajo] |
| M14 | **Electrónica** (B-BOX y lista de E4; README de electrónica §1–§9) | Caja de baterías en su bancada; las 2 baterías en paralelo con **un fusible por rama** de <!--V:sizing.electrical.fuse_branch_a:.0f-->150<!--/V--> A (Class T, a ≤ 175 mm de cada borne + [VERIFICADO: R06 §5.1]) a barras; F1 Class T de <!--V:sizing.electrical.fuse_a:.0f-->250<!--/V--> A junto a la barra +; toma de carga SB50 con F6; S1, K1 con R_pre, controlador sobre P1-ELE-01 con la capota P1-ELE-02; cable DC <!--V:sizing.electrical.cable_dc.section_mm2:.0f-->70<!--/V--> mm²; fases = cables propios del motor (6 AWG × 300 mm) y del ESC (8 AWG) unidos con balas de 8 mm (B-PHCON); terminales crimpados con termocontraíble con adhesivo; NTC10K de fábrica del motor (cable amarillo) a TEMP del VESC; caja IP67 de mando. **BAT− no va al casco** | **T0.1** aislación y **T0.2** tensiones antes de unir las baterías en paralelo |
| M15 | **Mandos** (consola de Jorge, P1-CTL-02/03/08–14) | Caja T85 + volante, cable M66 a la biela del yugo; unidad de palancas sobre la placa central P1-CTL-08 (2 × M6 por debajo de la tapa de la consola); Mach5 de la consola; gatillo P1-CTL-14 en su pasador Ø5 (ISO 2341-B + pasador de aletas, resorte de retorno, B-RELKIT) con la barra igualadora y los **dos** Bowden enganchados a ±8 de su pasador; las dos vainas apoyadas en la pestaña de tope de P1-CTL-10 con su regulador M6; hall con imán (entrehierro del plano); soporte del kill switch y seta | T0.5 calibración, T0.M6 enclavamiento, T0.10–T0.11 bucket con el firmware |

---

## 4. Aislamiento galvánico

Casco, placa base, conducto, placa de espejo y bucket son Al 5083: el mismo metal, sin par entre ellos (D-09). El riesgo está en el 316 en contacto con aluminio bajo el agua: ~670 mV de diferencia contra un límite práctico de 200 mV [VERIFICADO: R06 §6, Gerr].

| Par | Dónde | Medida | Control |
|---|---|---|---|
| Tornillería A4 ↔ Al | Ala de la placa base, bridas de la bomba, placa de espejo, brida del yugo, tope, pórtico | Tef-Gel en roscas y asientos + arandela de nylon bajo cabeza y tuerca (B-TEFGEL, B-ISOW) [VERIFICADO: R06 §6] | Visual al desarmar: sin polvo blanco alrededor de las cabezas |
| Anillo de desgaste 316 ↔ carcasa 6061 | Asiento prensado (sin anodizado: S-ANOD enmascara los asientos H7) | Loctite 648 en el prensado; ánodo | Inspección por la tobera al cambiar el pasador |
| Caja del sello 316 ↔ buje del conducto 5083 | Espigón y brida de 4 × M6 | Tef-Gel en el espigón y la cara; arandelas aislantes | Al desmontar el sello |
| Rejilla 316 ↔ bloque del labio y placa base 5083 | Ranuras y bolsillos, canto que apoya en la cuña, tornillos M5, bajo el agua | **Aislar**: camisa o cinta de PTFE en ranuras y bolsillos (el CAD deja <!--V:manifest.params.toma_iso_gap:.1f-->0.5<!--/V--> mm por lado), cinta de PTFE <!--V:manifest.params.toma_bar_iso_t:.1f-->0.2<!--/V--> mm en el canto que apoya en la cuña, arandelas cónicas de nylon bajo las cabezas avellanadas M5 y casquillo aislante en el agujero; Tef-Gel en las roscas; ánodo | Al montar: > 1 kΩ entre rejilla y placa base con el multímetro (sin los M5 puestos y después de apretarlos). Inspección mensual desde afuera |
| Pasador Al 6061 ↔ eje e impulsor 316 | Cubo del impulsor | Pasador consumible (§7); el Al es el ánodo: se corroe él, no el eje | Se cambia por mantenimiento |
| Pernos 316 ↔ boquilla 6061 y bucket 5083 | Pivotes | Bujes y arandelas de POM (P1-PMP-11, P1-STE-03, P1-REV-03): sin contacto metal-metal | Juego de los bujes (§7) |
| Émbolos 316 ↔ orejas 6061 de la boquilla (P1-REV-04; cuerpo ajustado desde el cierre de la ronda 5) | Cuerpo Ø<!--V:manifest.params.REV_lock_bore_d:g-->24<!--/V--> h6 en el Ø<!--V:manifest.params.REV_lock_bore_d:g-->24<!--/V--> H7 del lóbulo engrosado de la oreja, collar exterior Ø32 contra la cara exterior del lóbulo y arandela 316 + anillo DIN 471-24 A4 contra su cara interior | El agujero Ø<!--V:manifest.params.REV_lock_bore_d:g-->24<!--/V--> H7 se **enmascara** en el anodizado (ajuste): el cuerpo va con **Loctite 641** (B-LOCK243), que llena el juego H7/h6, evita el desgaste por roce y aísla el 316 del 6061 sin anodizar [SUPUESTO: el retenedor curado deja fuera el agua]; **sin Tef-Gel** en el ajuste; collar y arandela apoyan en caras **anodizadas** (S-ANOD: no enmascarar, aíslan) | Cada temporada (§7): el cuerpo no se mueve en la oreja; sin polvo blanco en el borde del collar ni junto al anillo |
| Perno de traba 316 ↔ agujeros del brazo 5083 y guía 316 del cuerpo (P1-REV-04 / P1-REV-01; re-auditoría ronda 5, DES-06) | El perno Ø<!--V:manifest.params.REV_lock_pin_d:g-->16<!--/V--> entra en los agujeros Ø<!--V:manifest.params.REV_lock_hole_d:g-->16.5<!--/V--> **sin anodizar** del brazo (escariados después de soldar), mojado, con 0,25 mm de rendija por lado: es el contacto 316 ↔ Al más cargado; además el perno 316 desliza en la guía 316 del cuerpo (H8/h9, juego 0–0,07): inox sobre inox puede **engranarse (galling)** | Tef-Gel en los agujeros del brazo y en el perno al montar (película fina: el perno tiene que entrar solo); en la guía, pasta antiengrane apta para inox (o la grasa de silicona de §7) [SUPUESTO: práctica]; el perno desliza con poca carga (solo el resorte), pero con la traba cargada apoya en la guía con ≈ 45 MPa de borde [CALCULADO: fila «Perno Ø16 en la guía del cuerpo» de P1-REV-04; re-auditoría del cierre de la ronda 5, CALC-3] | Cada temporada (§7): sacar el perno, mirar perno y agujeros (sin polvo blanco, picaduras ni marcas de engrane), limpiar y volver a poner Tef-Gel/pasta; **T0.M6b** |
| Casquillo dúplex del pivote ↔ oreja 6061 y muñón dúplex ↔ casquillo (P1-REV-02, en dos piezas desde la re-auditoría del cierre de la ronda 5, MECH-1) | Brida del casquillo contra la cara exterior de la oreja, piloto en el Ø<!--V:manifest.params.REV_sp_pilot_d:g-->24<!--/V--> H7 del lóbulo (lleva la carga del pivote), muñón en el Ø<!--V:manifest.params.REV_pin_d:g-->20<!--/V--> H7 del casquillo y en el buje POM, tornillo M12 y arandela ancha ISO 7093 por dentro, sobre el fondo del casquillo y la cara del lóbulo | La cara de apoyo de la oreja va **anodizada** (S-ANOD: no enmascararla, aísla), con Tef-Gel en la cara de la brida; el piloto, en su agujero **enmascarado**, con **Loctite 641** (llena el juego: sin roce bajo carga ni fretting, y aísla el dúplex del 6061 sin anodizar [SUPUESTO: el retenedor curado deja fuera el agua]; FEA-4; hasta la re-auditoría del cierre iba con Tef-Gel); el muñón con Tef-Gel (inox con inox); la rosca del M12 con Loctite 243 (R7), no Tef-Gel; arandelas ISO 7089 / ISO 7093 A4 | Al desarmar: sin polvo blanco bajo la brida ni en el muñón; cada temporada, juego del pivote (§7); el casquillo queda en la oreja al desmontar el bucket |
| Desbloqueo 316/A4 ↔ 5083/6061 | M5 del soporte P1-REV-09 en el pad de la boquilla; ejes 1.4401+C prensados en el montante de 5083 y pernos de manivela 1.4401+C prensados en los cubos de los balancines (5083); el balancín gira sobre un **casquillo polimérico** (sin contacto 316 ↔ 5083 en el giro) | Ejes y pernos prensados con Loctite 638 (llena el ajuste); Tef-Gel en las roscas M5 y arandela de nylon bajo las cabezas (B-RELKIT) | Cada temporada (§7) |
| Pasamuros M66 316 ↔ espejo 5083 | Sobre la flotación | Sikaflex + Tef-Gel + arandela aislante | — |
| Sistema eléctrico ↔ casco | BAT− y todo el circuito de potencia | Flotante: nada del circuito toca el casco [VERIFICADO: R06 §5.1, ISO 13297 4.1] | **T0.1** > 1 MΩ BAT− ↔ casco, BAT− ↔ eje, B+ ↔ casco, antes de cada temporada |
| Protección catódica | Carcasa / conducto | Ánodo de **aluminio** (no zinc en agua salobre) con continuidad eléctrica a la carcasa y al conducto (B-ANODE) [VERIFICADO: R06 §6, Fisheries Supply] | Continuidad ánodo ↔ conducto ↔ carcasa < 1 Ω con multímetro [SUPUESTO]; cambiar al 50 % consumido o una vez por año [VERIFICADO: R06 §6] |

Nada de latón ni de fibra de carbono bajo el agua [VERIFICADO: R06 §0, §6]. Los insertos de latón (B-INS) van solo en la base y la capota del controlador, que son piezas secas.

---

## 5. Pruebas por etapas

No se pasa de etapa si una prueba no pasa. Cada prueba deja un registro: fecha, quién, valores medidos, fotos o video, log del VESC exportado. Criterios numéricos desde `sizing.json → success.*` (factores en `inputs.yaml → operation.success` [SUPUESTO]) y 02 §11.

### T0 — Banco en seco (bote en tierra o en el trailer)

**Condición:** acople desconectado (estrella sacada; correr el motor hacia proa sobre sus pies): el sello no gira en seco (R2). Extintor ABC a mano.

| # | Prueba | Cómo | Pasa si | Si no pasa |
|---|---|---|---|---|
| T0.0–T0.20 | Electrónica, kill switch y firmware | README de electrónica §10 (compilación del sketch y FW ≥ 6.00 del VESC con respaldo del XML, aislación, tensiones, precarga, contactor, calibración, configuración del VESC, arranque con acelerador abierto, rampa, bucket, kill por cordón y seta 10/10, barreras independientes, falla de sensor, pérdida de PPM, watchdog, vida del interruptor, perfil COSTA/ABIERTO) | Los criterios de esa tabla; en particular corte < 1 s en 10/10 (T0.12–T0.13) | Corregir y repetir la prueba entera. Sin T0.12–T0.15 aprobadas no hay T2 |
| T0.M1 | Giro libre | A mano en el cubo del acople, 3 vueltas lentas, después de M7, M8 y M11 | Sin roce, sin punto duro, sin ruido de contacto del impulsor con el anillo | Desarmar: buscar el contacto (marca brillante en el anillo o en las puntas) |
| T0.M2 | Holgura de punta | Galgas en 4 posiciones del anillo × 4 posiciones angulares del impulsor (girando a mano) | 0,3–0,4 mm radial en las 16 lecturas [ESTIMADO: R12 §2.7]; diseño <!--V:manifest.params.tip_clr:.2f-->0.40<!--/V--> mm, concentricidad del anillo ≤ <!--V:manifest.params.pmp_ring_TIR:.2f-->0.05<!--/V--> mm | Diferencia > 0,1 mm entre lecturas: excentricidad del eje (revisar el centrado del pórtico, paso M7). Holgura < 0,3: el taller repasa el anillo; > 0,4: anillo nuevo |
| T0.M3 | Juego axial y vibración | Comparador 0,01 mm en la cara del cubo del acople, empujar y tirar a mano del eje; golpe de martillo de goma en el eje montado con el celular apoyado (app de espectro) | Juego axial ≤ el juego axial del par 7204 BECBP en O de la ficha SKF (apareo CB, del orden de centésimas [ESTIMADO: verificar en la ficha]); con 7204 BEGAP (precarga ligera) no perceptible (< 0,01 mm); primera frecuencia propia > rpm máx. (<!--V:sizing.mech.n_max_rpm:.0f-->4182<!--/V--> rpm) / 60 con margen; el cálculo da <!--V:sizing.mech.crit_ratio:.1f-->3.8<!--/V--> × [CALCULADO; método de 02 §12] | Juego: KM4 floja o rodamientos no apareados. Frecuencia baja: revisar el buje de agua (2.º apoyo) |
| T0.M4 | Alineación del acople | Comparador sobre el cubo del lado del motor, girando a mano; galgas entre cubos en 4 posiciones | Separación entre cubos <!--V:manifest.params.drv_coupling.s:.1f-->2.0<!--/V--> mm en las 4 posiciones; desalineación radial y angular dentro de la tabla de KTR para Rotex 24 (pedirla con el acople: no está en el repositorio) | Calzar los pies del motor; repetir |
| T0.M5 | Motor solo | VESC Tool: detección del motor (FOC), sentido de giro, pares de polos, lectura del NTC | Gira en el sentido de la bomba: <!--V:manifest.params.pmp_rot_sense:-->antihorario visto desde popa (+X, regla de la mano derecha)<!--/V-->; pares de polos anotados en `inputs.yaml` y `run_all.py` corrido (cambia el tope de ERPM de COSTA: sizing da <!--V:sizing.legal_speed.erpm_cap:.0f-->9259<!--/V--> ERPM y el VESC carga `l_max_erpm` de `04_diseno/electronica/electronica.json`, redondeado a 100 hacia abajo [CALCULADO con 5 pares de polos de `inputs.yaml`]); NTC a temperatura ambiente ±3 °C [SUPUESTO] | Sentido: invertir dos fases o el parámetro del VESC. Pares de polos distintos: volver a cargar `l_max_erpm` (T0.6, T0.20) |
| T0.M6 | Mandos mecánicos | Volante tope a tope; palanca del bucket con el acelerador en 0 y fuera de 0; gatillo | Boquilla ±<!--V:manifest.params.steer_max:.0f-->25<!--/V-->° y para en el tope mecánico; el bucket baja y sube completo y **las dos trabas** entran solas en las dos posiciones (detalle en T0.M6b); con el acelerador fuera de 0 la palanca del bucket no se mueve (enclavamiento); **galga de 0,5 mm entre cada brazo del bucket y el collar de su émbolo en todo el giro** (entra en todo el recorrido [SUPUESTO: re-auditoría del cierre de la ronda 5, MECH-8]; el collar queda a 1,0 mm del brazo [CALCULADO: check de P1-REV-04]) | Ajustar terminales del M66/Mach5 y los dos Bowden; nunca sacar el tope. Galga que no entra: brazo torcido por la soldadura (05 §4, cara interior ≤ 0,3 mm) o collar sin apoyar en el lóbulo: no usar la reversa y avisar a DIRECCIÓN |
| T0.M6b | **Prueba funcional de las dos trabas** (ronda 4: criterio de traba única; reemplaza el ensayo de desfase con comparador) | Con la palanca: bucket ABAJO, soltar el gatillo. Mirar cada pomo y medir con el calibre de profundidad cuánto sobresale cada perno de la cara exterior de su brazo. Apretar el gatillo: los dos pernos salen y el bucket sube; soltarlo en ARRIBA y repetir. **10 ciclos** ABAJO → ARRIBA → ABAJO. En uno de los ciclos, medir con dinamómetro en el punto de apoyo de los dedos la fuerza del gatillo que saca los dos pernos | 10/10 en las dos posiciones: **los dos pernos entran solos (resorte)** sin empujar el bucket con la mano, **sobresalen 0,5–1,5 mm** de la cara exterior del brazo (diseño 1 mm [CALCULADO: `piezas/_release.pin_tip_y`]; el límite superior es de la re-auditoría del cierre de la ronda 5, MECH-2 [SUPUESTO]: más sobresalida es cola larga o pomo fuera de lugar y come la carrera que libera el brazo) y **salen los dos con el gatillo**; fuerza para liberar ≤ 100 N [SUPUESTO: fuerza de diseño de la mano; se espera ≈ 93 N = 2 cables × <!--V:manifest.parts.14.checks.5.ref:.1f-->98.8<!--/V--> N × 15,86 / (35,4 × 0,95) [CALCULADO: resorte final ≈ 45 N / (η Bowden 0,6 · η balancín <!--V:manifest.parts.14.checks.6.value:.2f-->0.76<!--/V-->), brazos y η 0,95 del gatillo P1-CTL-14; resorte y rendimientos ESTIMADOS]: el margen es chico (≈ 7 %), un resorte duro lo consume (PENDIENTES P1.8)]. Repetir cada temporada y después de tocar el bucket, los pivotes o los Bowden | Sobresale > 1,5 mm: repetir el control en banco de M13 (punta a 10,0 ± 0,2 del collar). Un perno no entra: cable tenso (aflojar el regulador), eslabón mal ajustado (rehacer el orden de M13: eslabón primero, regulador después), sal o grasa seca (desarmar y limpiar), agujero fuera de posición (05 §4, paso 4). No salen: regular los Bowden. Fuerza alta: radios de la vaina (≥ R30), camisa de PTFE dañada. **No usar la reversa con una sola traba entrada** (checklist): la segunda es la redundancia |
| T0.M7 | Circuito de refrigeración | Agua de red a baja presión en la espiga de la carcasa, 5 min | Sale chorro continuo por el testigo del espejo; ninguna gota en espigas, filtro, caja de agua ni camisa | Rehacer la unión; abrazaderas nuevas |
| T0.M8 | Achique y alarma | Agua en la sentina hasta el flotante, con S1 en OFF y el cordón afuera | Bomba arranca sola y desagota por el pasacasco; alarma suena con el nivel alto | Revisar el DC-DC de 12 V y F4: tienen que estar aguas arriba de S1/K1 |

### T1 — Estanqueidad, flotación y escora

**T1.1 bloquea todo lo demás** (R13 §5; D-04). Se hace primero con el casco sin cortar y lastre equivalente (antes de comprar), y se repite con el equipo instalado.

| # | Prueba | Cómo | Pasa si | Si no pasa |
|---|---|---|---|---|
| T1.1 | **E1 — escora con carga desplazada** | En el muelle, agua calma. Masa de diseño <!--V:sizing.masses.total_kg:.0f-->219<!--/V--> kg con lastre; piloto de 100 kg o lastre equivalente con su CG ≥ 100 mm sobre el asiento, desplazado 0,1 m, 0,2 m y hasta la borda. Inclinómetro del celular, francobordo con regla | Sin entrada de agua; francobordo residual ≥ 100 mm; escora ≤ 15° con el piloto a 0,2 m de crujía [SUPUESTO: umbrales de R13 §5; método: ISO 12217-3 ESTIMADO y 33 CFR 183.230 VERIFICADO] | El cálculo da GM = <!--V:sizing.hydrostatics.GM_m:.3f-->0.010<!--/V--> m y <!--V:sizing.heel_pilot_0p1m_deg:.0f-->76<!--/V-->° con 0,1 m [CALCULADO, casco ESTIMADO]: lo esperable es que falle. Cambio de casco (manga en la flotación ≥ 0,9 m, flotadores laterales, asiento más bajo) y repetir. **No se sigue** |
| T1.2 | Calado y cebado geométrico | Todo instalado, piloto a bordo, agua del fiordo: medir el calado en el espejo, en crujía, y la altura de la tapa de la chimenea sobre el agua | Eje del impulsor (a <!--V:sizing.priming.axis_height_m:.3f-->0.115<!--/V--> m de la quilla) ≥ 20 mm bajo la flotación [VERIFICADO: R10a §3.2, §8.1]; cálculo: <!--V:sizing.priming.axis_below_wl_m:.3f-->0.172<!--/V--> m bajo; tapa ≥ 60 mm sobre el agua; todos los pasos del espejo sobre el agua | Eje alto: no ceba → bajar el eje (`h_axis`) y rehacer la toma. Tapa baja: alargar la chimenea |
| T1.3 | Estanqueidad a flote | 24 h amarrado, sistema sin girar, sentina seca y fotografiada al empezar | Sentina seca a las 24 h; testigo del sello seco; sin agua alrededor de la placa base, la placa de espejo ni los pasacascos [VERIFICADO: R10a §8.5] | Localizar con papel tisú; sacar el bote antes de que la batería toque agua. Rehacer el Sikaflex o el sello |
| T1.4 | E2 — inundado | **Sin baterías, motor ni controlador**: lastre inerte de igual peso sumergido; llenar de agua; más 2/15 del peso del piloto sumergido; 18 h | Flota; idealmente nivelado, escora ≤ 10° [VERIFICADO: 33 CFR 183.105 / 183.225] | Más flotación (C7) y repartirla mejor; repetir |
| T1.5 | E3 — inundado con carga desplazada | Como T1.4 con medio peso de persona en una banda | Escora ≤ 30° [VERIFICADO: 33 CFR 183.230] | Ídem |
| T1.6 | E4 — reabordaje | Persona con chaleco, desde el agua, sin ayuda ni escalera auxiliar | Sube sin volcar el bote [VERIFICADO: RCD 2.3, vía R13 §5] | Escalón o asa de reabordaje en el espejo, lejos de la boquilla; repetir |

### T2 — Muelle, amarrado

Bote amarrado de proa a un punto fijo con el dinamómetro en el cabo, en ≥ 1 m de agua libre bajo la toma, sin bañistas. Piloto a bordo con chaleco y cordón. VESC Tool registrando (corriente, rpm, temperaturas, fallas).

| # | Prueba | Cómo | Pasa si | Si no pasa |
|---|---|---|---|---|
| T2.1 | Purga y cebado | Purgar la chimenea (sale agua por el tornillo, cerrar); arrancar a rpm bajas | Chorro continuo por la tobera en ≤ 3 s [SUPUESTO: R10a §8.4] | Cortar; volver a purgar; revisar el O-ring de la tapa (si entra aire la bomba se desceba) |
| T2.2 | Refrigeración | Testigo del espejo al arrancar; caudal con jarra graduada y cronómetro a <!--V:sizing.legal_speed.n_legal_rpm:.0f-->2505<!--/V--> rpm (las de 5 kn) | Sale agua por el testigo en el primer minuto; caudal ≥ <!--V:sizing.cooling.Q_l_min_legal:.1f-->3.2<!--/V--> L/min [CALCULADO a 5 kn; a punto fijo la altura de la bomba es mayor con las mismas rpm] | Parar. Filtro tapado, manguera aplastada u orificio obstruido |
| T2.3 | Testigo del sello | Ventanas de la linterna y manguera testigo durante T2.1–T2.6 | Seco: ≤ 1 gota por minuto [SUPUESTO] | Parar; cambiar el sello (R-SEAL); revisar que no haya girado en seco |
| T2.4 | Dirección y bucket con chorro | Ralentí; volante tope a tope; bucket abajo **con el acelerador en 0**, reversa al límite del firmware, dinamómetro en el cabo de popa | Boquilla sin vibración ni golpe en los topes; reversa ≥ 0,8 × <!--V:sizing.performance.reverse_N:.0f-->217<!--/V--> N del modelo [SUPUESTO: mismo factor que el punto fijo]; las dos trabas sostienen el bucket abajo | Reversa débil: revisar el recorrido del bucket (<!--V:manifest.params.bucket_down_deg:.0f-->70<!--/V-->° en el CAD) |
| T2.5 | **Rampa de punto fijo** | Escalones de 25 % de acelerador hasta fondo, 10 s cada uno; dinamómetro, rpm y corriente de batería | Empuje a fondo ≥ <!--V:sizing.success.bollard_min_N:.0f-->612<!--/V--> N (modelo <!--V:sizing.performance.bollard_N:.0f-->765<!--/V--> N) [CALCULADO]; corriente de batería ≤ <!--V:sizing.electrical.I_bat_limit_A:.0f-->192<!--/V--> A; rpm a fondo cerca del tope de punto fijo (<!--V:sizing.performance.peak_curve.0.n_rpm:.0f-->4045<!--/V--> rpm) | **No pasa** si las rpm suben con el empuje plano o hay ruido de grava (cavitación o aire) [VERIFICADO como síntoma: R10a §8.7]: rejilla, purga, tope de ERPM del perfil abierto (02 §4.6). Empuje bajo sin cavitación: holgura de punta, η de la bomba (bloqueo H-3) |
| T2.6 | Temperaturas | 3 min a fondo amarrado, después 5 min a ralentí; NTC del motor, temperatura del controlador (VESC) y del agua del testigo | Motor ≤ <!--V:sizing.thermal.T_motor_steady_C:.0f-->49<!--/V--> °C + 20 K [CALCULADO estacionario a V máx. + margen SUPUESTO] y siempre < <!--V:sizing.thermal.t_winding_max_C:.0f-->120<!--/V--> °C; sin recorte térmico en el log; agua del testigo tibia, ΔT ≤ 15 K [SUPUESTO: `inputs.yaml` cooling.dT_max_k; cálculo <!--V:sizing.cooling.dT_water_K:.1f-->1.9<!--/V--> K] | Revisar caudal (T2.2); pedir a Maytech el caudal de la camisa |
| T2.7 | Kill en el agua | Motor al 30 %: tirar del cordón; 5 veces; luego la seta | Sin empuje en < 1 s (video); al reponer el cordón con el acelerador abierto no arranca; 5/5 | Volver a T0.12–T0.15 |
| T2.8 | Limpieza de rejilla | Acelerador en 0, pulsador sostenido | Reversa lenta que dura ≤ 3 s y suelta lo atrapado (T0.11 b) | Revisar el firmware (README §5.2) |
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

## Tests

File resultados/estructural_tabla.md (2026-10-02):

<!-- generado por 04_diseno/structural.py -->
| Pieza | Caso de carga | Modelo | σ [MPa] | Admisible | S [MPa] | FS | Obj. | OK |
|---|---|---|---|---|---|---|---|---|
| P1-PMP-03 | Álabe en la raíz: par de diseño 15.3 N·m + empuje | voladizo: F_t=T/(Z·r_m)=62 N a span/2 + F_a=153 N/álabe en r̄; M=2.98 N·m; W_mín perfil cubo=79 mm³ (c=53.9, t=4.31) | 37.94 | metal | 205.0 | 5.4 | 2.0 | ✔ |
| P1-PMP-03 | Álabe en la raíz, fatiga: par de diseño 15.3 N·m + empuje | σ_a = 0.30·σ_m (paso por 7 álabes del estator, toma); K_f 1.5; S_e 316 | 11.38 | metal | 120.0 | 10.54 | 2.0 | ✔ |
| P1-PMP-03 | Álabe en la raíz: par máx. del controlador 18.6 N·m + empuje | voladizo: F_t=T/(Z·r_m)=75 N a span/2 + F_a=153 N/álabe en r̄; M=3.06 N·m; W_mín perfil cubo=79 mm³ (c=53.9, t=4.31) | 38.97 | metal | 205.0 | 5.26 | 2.0 | ✔ |
| P1-PMP-03 | Álabe en la raíz, fatiga: par máx. del controlador 18.6 N·m + empuje | σ_a = 0.30·σ_m (paso por 7 álabes del estator, toma); K_f 1.5; S_e 316 | 11.69 | metal | 120.0 | 10.26 | 2.0 | ✔ |
| P1-PMP-03 | Álabe en la raíz: par de corte del pasador 33.5 N·m (traba repartida) | voladizo: F_t=T/(Z·r_m)=135 N a span/2 + F_a=153 N/álabe en r̄; M=3.58 N·m; W_mín perfil cubo=79 mm³ (c=53.9, t=4.31) | 45.57 | metal | 205.0 | 4.5 | 2.0 | ✔ |
| P1-PMP-03 | Cubo: aplastamiento del semipasador al par de corte | F = T_corte/(2·r_eje) = 1674 N por lado sobre el tramo interior 3.5×5.0 mm (la ranura aligerante deja 5.0 + 4.0 mm de contacto; conservador: solo el interior) | 95.66 | metal | 307.5 | 3.21 | 2.0 | ✔ |
| P1-PMP-05 | Par máx. del controlador (margen contra corte intempestivo) | 2 semipasadores, 2 secciones de corte a r_eje: τ=T/(d_eje·A)=96.5 MPa; τ_u=0,6·S_u=174 MPa; T_corte/T_máx=1.80 (criterio R12 ≥ 1,5) | 96.50 | metal | 174.0 | 1.8 | 2.0 | ✔ (justif.) |
| P1-PMP-05 | Fatiga a par de crucero (Goodman en corte) | τ_m=73.7, τ_a=11.1 MPa (T_top 14.2 N·m, ±15%); S_e,τ=0,577·S_e; índice Goodman 0.62 | 0.62 | metal | 1.0 | 1.6 | 2.0 | ✔ (justif.) |
| P1-PMP-06 | Álabe del estator en la raíz: par de diseño 15.3 N·m | voladizo (conservador, en realidad empotrado en camisa y cubo): F_t=44 N, F_a=36 N, F_r buje=26 N; W_mín=70 mm³ (c=44.4, t=4.44) | 25.79 | metal | 240.0 | 9.31 | 2.0 | ✔ |
| P1-PMP-06 | Álabe del estator, fatiga: par de diseño | σ_a=0.30·σ_m (estelas de 5 álabes); S_e Al anodizado = 0.6·S_e; K_f 1.5 | 7.74 | metal | 38.4 | 4.96 | 2.0 | ✔ |
| P1-PMP-06 | Álabe del estator en la raíz: par máx. del controlador 18.6 N·m | voladizo (conservador, en realidad empotrado en camisa y cubo): F_t=54 N, F_a=36 N, F_r buje=26 N; W_mín=70 mm³ (c=44.4, t=4.44) | 27.59 | metal | 240.0 | 8.7 | 2.0 | ✔ |
| P1-PMP-06 | Álabe del estator, fatiga: par máx. del controlador | σ_a=0.30·σ_m (estelas de 5 álabes); S_e Al anodizado = 0.6·S_e; K_f 1.5 | 8.28 | metal | 38.4 | 4.64 | 2.0 | ✔ |
| P1-PMP-01 | Presión interna 0.20 MPa (R12 §7.2) | aro delgado σ=p·r/t, r=73.9, t=5.0 | 2.96 | metal | 240.0 | 81.2 | 2.0 | ✔ |
| P1-PMP-08 | Presión interna 0.20 MPa (R12 §7.2) | aro delgado σ=p·r/t, r=68.9, t=5.0 | 2.76 | metal | 240.0 | 87.09 | 2.0 | ✔ |
| P1-PMP-01 | Bulones brida toma (8×M6): presión + bucket + momentos | F_ax=3857 N (p hasta el sello Ø152.3), M=242.2 N·m (boquilla 364 N, bucket 1408 N, peso) → F_bulón=1217 N sobre A_s=20.1 mm² (sin precarga) | 60.54 | metal | 450.0 | 7.43 | 2.0 | ✔ |
| P1-PMP-08 | Bulones brida carcasa–tobera (8×M5 roscados): presión + bucket + momentos | F_ax=3419 N (p hasta el sello Ø142.8), M=182.8 N·m (boquilla 364 N, bucket 1408 N, peso) → F_bulón=1029 N sobre A_s=14.2 mm² (sin precarga) | 72.49 | metal | 450.0 | 6.21 | 2.0 | ✔ |
| P1-PMP-01 | Rosca M5 de la brida trasera en Al 6061-T6: precarga + servicio | barrido τ = F/(π·d·L·0,6), L engranada = 7.75 mm (M5 × 20), F_v = 3000 N [ESTIMADO] + 1029 N | 55.17 | metal | 138.5 | 2.51 | 2.0 | ✔ |
| P1-PMP-01 | Tornillos anti-rotación del estator (2×M5) al corte | F=130 N por tornillo (T_max 18.6 N·m, r=71.4), corte en A_s | 9.16 | metal | 259.6 | 28.35 | 2.0 | ✔ |
| P1-PMP-06 | Camisa: aplastamiento de la punta del M5 anti-giro al par máx. | σ_b = F/(d·h), h = 3.5 mm (agujero liso Ø5.5) | 7.43 | metal | 360.0 | 48.45 | 2.0 | ✔ |
| P1-PMP-09 | Oreja: aplastamiento del alojamiento del buje — F lateral de la boquilla 364 N | σ_b=F/(d·t), d=12.0, t=25.5 | 1.19 | metal | 187.5 | 157.87 | 2.0 | ✔ |
| P1-PMP-09 | Oreja: sección neta y desgarro — F lateral de la boquilla 364 N | máx(F/((w−d)·t), F/(2·(e−d/2)·t)·√3), w=24.0, e=12.0 | 2.06 | metal | 125.0 | 60.76 | 2.0 | ✔ |
| P1-PMP-09 | Oreja: flexión en el arranque — F lateral de la boquilla 364 N | M=F·15.0 mm, W=w·t²/6 (eje débil) | 2.09 | metal | 125.0 | 59.73 | 2.0 | ✔ |
| P1-PMP-09 | Oreja: fatiga — F lateral de la boquilla 364 N | σ_a = σ flexión (maniobras, ~1e5–1e6 ciclos); S_e 5083; K_f 1.5 | 2.09 | metal | 73.3 | 35.04 | 2.0 | ✔ |
| P1-PMP-11 | Buje de pivote POM: presión — F lateral de la boquilla 364 N | p=F/(d·L), d=8.0, L=25.5 (un solo buje) | 1.78 | metal | 25.0 | 14.03 | 2.0 | ✔ |
| P1-PMP-09 | Oreja: aplastamiento del alojamiento del buje — F del bucket 1408 N | σ_b=F/(d·t), d=12.0, t=25.5 | 4.59 | metal | 187.5 | 40.81 | 2.0 | ✔ |
| P1-PMP-09 | Oreja: sección neta y desgarro — F del bucket 1408 N | máx(F/((w−d)·t), F/(2·(e−d/2)·t)·√3), w=24.0, e=12.0 | 7.96 | metal | 125.0 | 15.71 | 2.0 | ✔ |
| P1-PMP-09 | Oreja: flexión en el arranque — F del bucket 1408 N | M=F·15.0 mm, W=w·t²/6 (eje débil) | 8.10 | metal | 125.0 | 15.44 | 2.0 | ✔ |
| P1-PMP-09 | Oreja: fatiga — F del bucket 1408 N | σ_a = σ flexión (maniobras, ~1e5–1e6 ciclos); S_e 5083; K_f 1.5 | 8.10 | metal | 73.3 | 9.06 | 2.0 | ✔ |
| P1-PMP-11 | Buje de pivote POM: presión — F del bucket 1408 N | p=F/(d·L), d=8.0, L=25.5 (un solo buje) | 6.89 | metal | 25.0 | 3.63 | 2.0 | ✔ |
| P1-PMP-09 | Bulones placa–espejo (6×M6): F del bucket 1408 N + momento | brazo 36 mm al espejo; F_bulón=413 N sobre A_s=20.1 mm² | 20.53 | metal | 450.0 | 21.92 | 2.0 | ✔ |
| P1-PMP-09 | Cuello: F lateral de la boquilla con el O-ring a tope | voladizo del cuello M=F·L=6.0 N·m, W anillo=116736 mm³ | 0.05 | metal | 125.0 | 2444.39 | 2.0 | ✔ |
| P1-STE-01 | Flexión del tubo por el desvío del chorro (fatiga, sizing) | M = F_s·e = 323 N × 66 mm; Z tubo Ø101.1/Ø91.1 | 0.62 | metal | 90.0 | 145.93 | 2.0 | ✔ |
| P1-STE-01 | Oreja del bucket: flexión en su plano (R12, corta; pivote + traba con M_h completo) | M raíz = 99 N·m (pivote a 52 mm + traba a r 45); sección 14 × 36 | 32.88 | metal | 240.0 | 7.3 | 2.0 | ✔ |
| P1-STE-01 | Oreja del bucket: flexión (reversa sizing, fatiga; M_h completo en su traba) | M raíz = 49.0 N·m; 14 × 36 | 16.31 | metal | 90.0 | 5.52 | 2.0 | ✔ |
| P1-STE-01 | Oreja: aplastamiento del cuerpo ajustado Ø24 del émbolo con fuerza y momento del perno (R12) | p_máx = F/(d·L)·(1 + 6·a/L): F 3006 N, a = 18.25 mm (mitad del brazo → plano medio del agujero), L 23.5 | 30.17 | metal | 240.0 | 7.96 | 2.0 | ✔ |
| P1-STE-01 | Oreja: ligamentos del agujero Ø24 del émbolo con la presión lineal (R12, M_h completo) | zona exterior 14.3 mm con F_+ = 5167 N, interior 9.2 mm con -2160 N; ligamentos 8 (placa) y 6 (hacia adentro) | 39.18 | metal | 240.0 | 6.13 | 2.0 | ✔ |
| P1-STE-01 | Oreja: ligamentos del agujero Ø24 del émbolo (reversa sizing, fatiga) | ídem con F = 1491 N | 19.43 | metal | 90.0 | 4.63 | 2.0 | ✔ |
| P1-STE-01 | Oreja del bucket: flexión fuera del plano por el pivote en voladizo (R12, M_h completo) | M = R_pivote 3302 N × 14.5 mm en la cara; raíz 36 × 14 | 40.71 | metal | 240.0 | 5.9 | 2.0 | ✔ |
| P1-STE-01 | Oreja de pivote (dentro de la de la bomba): flexión de la raíz | F = √((F_b/2)²+(F_s/2)²) = 727 N a 12 mm; 25 × 30 | 2.33 | metal | 240.0 | 103.14 | 2.0 | ✔ |
| P1-STE-02 | Hombro Ø8 biempotrado: flexión + corte (bucket R12 + dirección, corta) | reacción superior 1490 N en luz 28.5 mm (M = F·L/8); 316 estirado | 111.17 | metal | 310.0 | 2.79 | 2.0 | ✔ |
| P1-STE-02 | Hombro Ø8: flexión por maniobras (fatiga) | F_s/2 = 162 N, M = F·L/8 | 11.47 | metal | 180.0 | 15.7 | 2.0 | ✔ |
| P1-STE-05 | Hombro Ø8 en voladizo: flexión + corte (corta) | reacción inferior 195 N a 14.3 mm | 56.20 | metal | 310.0 | 5.52 | 2.0 | ✔ |
| P1-STE-05 | Hombro Ø8 en voladizo: flexión por maniobras (fatiga) | F_s/2 = 162 N a 14.3 mm | 45.87 | metal | 180.0 | 3.92 | 2.0 | ✔ |
| P1-STE-02 | Presión en el buje POM de la oreja de la bomba (P1-PMP-11) | 1490 N / (Ø8 × 25.5) | 7.29 | metal | 20.0 | 2.74 | 2.0 | ✔ |
| P1-STE-03 | Arandela POM: empuje axial (peso boquilla + bucket + componente vertical) | 60 N [ESTIMADO] / 199 mm² | 0.30 | metal | 10.0 | 33.18 | 2.0 | ✔ |
| P1-STE-06 | Poste Ø22: flexión + torsión (biela M66, M_s con F_s R12) | F_biela = M_s/86 mm = 279 N a 138 mm de la brida | 37.78 | metal | 240.0 | 6.35 | 2.0 | ✔ |
| P1-STE-06 | Poste Ø22: flexión (fatiga, sizing) | F_biela = 248 N | 32.84 | metal | 90.0 | 2.74 | 2.0 | ✔ |
| P1-STE-06 | Brida del poste: 4 × M8 A4-70 en Ø32 (tracción) | F = 4M/(n·BC) = 1209 N; As 36,6 mm² | 33.02 | metal | 450.0 | 13.63 | 2.0 | ✔ |
| P1-STE-04 | Banda de la brida: torsión (momento del poste) + flexión | T = 38.7 N·m en 24 × 20 (α = 0.217); F_biela × 86 mm | 34.48 | metal | 125.0 | 3.63 | 2.0 | ✔ |
| P1-STE-04 | 4 × M8 A4-70 a la torre: tracción por el momento del poste | F = M/(19 mm)/2 = 1018 N por bulón | 27.81 | metal | 450.0 | 16.18 | 2.0 | ✔ |
| P1-STE-08 | Placa de topes 8 mm: flexión en su plano (timón forzado) | F = 2·F_biela = 559 N a 90 mm del ala; sección 32 × 8 | 36.84 | metal | 125.0 | 3.39 | 2.0 | ✔ |
| P1-STE-06 | Poste contra el tope: flexión (timón forzado) | F = 559 N a 111 mm de la brida | 59.56 | metal | 240.0 | 4.03 | 2.0 | ✔ |
| P1-STE-08 | 2 × M6 A4-70 del ala al espejo (tracción por el momento) | M = F × 40 mm / 30 mm entre bulón y borde | 37.07 | metal | 450.0 | 12.14 | 2.0 | ✔ |
| P1-STE-07 | Brazo 10 mm: flexión por la altura de la rótula + tracción | F_biela 279 N; M = F × 12 mm en 24 × 10 | 9.55 | metal | 125.0 | 13.09 | 2.0 | ✔ |
| P1-REV-01 | Chapa de la cuchara: franja empotrada bajo la presión dinámica (corta) | p = 98 kPa, luz 57.5 mm (nervio central), t = 8 | 2.53 | metal | 125.0 | 49.48 | 2.0 | ✔ |
| P1-REV-01 | Chapa de la cuchara: franja (fatiga de soldadura, 1e5) | ídem | 2.53 | metal | 68.0 | 26.92 | 2.0 | ✔ |
| P1-REV-01 | Cuchara como viga entre brazos (bucket R12, corta) | M = F·L/8, L = 115; I_arco = 547e3 mm⁴ | 1.82 | metal | 125.0 | 68.59 | 2.0 | ✔ |
| P1-REV-01 | Brazo trabado: flexión en su plano con M_h completo (R12, corta) | M = M_h = 135 N·m en un brazo; sección 8 × 60 | 28.18 | metal | 125.0 | 4.44 | 2.0 | ✔ |
| P1-REV-01 | Brazo trabado: flexión en su plano con M_h completo (reversa sizing, fatiga de soldadura) | M = M_h,sizing = 67 N·m | 13.98 | metal | 68.0 | 4.86 | 2.0 | ✔ |
| P1-REV-01 | Cuchara abierta a torsión con un solo brazo trabado (R12, corta) | T = M_h = 135 N·m en la unión con el brazo trabado; τ = T·t/J, J = s·t³/3 (s = 190) | 57.73 | metal | 125.0 | 2.17 | 2.0 | ✔ |
| P1-REV-01 | Cuchara abierta a torsión con un solo brazo trabado (reversa sizing, fatiga de soldadura) | T = M_h,sizing = 67 N·m; τ en la soldadura brazo–cuchara | 28.64 | metal | 68.0 | 2.37 | 2.0 | ✔ |
| P1-REV-01 | Agujero de traba: aplastamiento del brazo (perno Ø16, M_h completo, R12) | F = M_h/r = 135 N·m / 45 mm = 3006 N | 23.49 | metal | 125.0 | 5.32 | 2.0 | ✔ |
| P1-REV-01 | Pivote: aplastamiento del brazo + aro (buje Ø24 × 18), R12 | R_pivote = 3302 N (chorro/2 + traba con M_h completo) | 7.64 | metal | 125.0 | 16.35 | 2.0 | ✔ |
| P1-REV-02 | Muñón Ø20/Ø12.5 (dúplex): precarga máxima del M12 + flexión y corte (R12, una traba) | F_máx/A = 6.7 kN / 191 mm² + R = 3302 N a 10.5 mm de la brida; τ = 2V/A (tubo) | 105.47 | metal | 450.0 | 4.27 | 2.0 | ✔ |
| P1-REV-02 | Muñón: flexión (reversa sizing, fatiga; una traba; la precarga es media de compresión) | R = 1638 N | 25.84 | metal | 180.0 | 6.97 | 2.0 | ✔ |
| P1-STE-01 | Oreja: aplastamiento del piloto Ø24 con corte y momento del pivote (R12, unión deslizada) | p_máx = R/(d·L)·(1 + 6·a/L): R 3302 N, a = 24.5 mm (al plano medio del agujero), L 20 | 57.44 | metal | 240.0 | 4.18 | 2.0 | ✔ |
| P1-STE-01 | Oreja: ligamentos del agujero Ø24 del piloto con la presión lineal (R12, M_h completo) | zona exterior 11.4 mm con F_+ = 7830 N, interior 8.6 mm con -4529 N; ligamento 10 | 59.75 | metal | 240.0 | 4.02 | 2.0 | ✔ |
| P1-STE-01 | Oreja: ligamentos del agujero Ø24 del piloto (reversa sizing, fatiga) | ídem con R = 1638 N | 29.64 | metal | 90.0 | 3.04 | 2.0 | ✔ |
| P1-REV-02 | Muñón Ø20/Ø12.5 (dúplex) dentro del casquillo, en la cara de la oreja: flexión + corte (R12, una traba) | M = R 3302 N × 14.5 mm = 47.9 N·m (sin contar el casquillo); τ = 2V/A | 93.51 | metal | 450.0 | 4.81 | 2.0 | ✔ |
| P1-REV-02 | Casquillo: aplastamiento del muñón en su agujero Ø20 H7 (R12, ×1,4 por el juego) | p_máx = 1,4·R/(d·L)·(1 + 6·a/L): L 20, a 20.5 mm | 82.63 | metal | 450.0 | 5.45 | 2.0 | ✔ |
| P1-REV-02 | Fondo del casquillo entre el muñón y la arandela interior: compresión con la precarga máxima | 6.7 kN / corona Ø20/Ø12.5 | 34.82 | metal | 450.0 | 12.92 | 2.0 | ✔ |
| P1-REV-02 | Brida sobre la oreja 6061: presión con la precarga máxima | 6.7 kN / corona Ø36/Ø25 = 527 mm² | 12.65 | metal | 240.0 | 18.97 | 2.0 | ✔ |
| P1-STE-01 | Arandela ISO 7093 Ø37 por dentro de la oreja: presión con la precarga máxima | 6.7 kN / corona Ø37/Ø25 = 584 mm² | 11.41 | metal | 240.0 | 21.04 | 2.0 | ✔ |
| P1-REV-02 | Tornillo M12 A4-80 al montar con la precarga máxima: σ_red ≈ 1,15·F/A_s ≤ 0,9·Rp0,2 (VDI 2230) | 6.7 kN / 84,3 mm²; torsión de la rosca ≈ +15 % [ESTIMADO] | 90.94 | metal | 540.0 | 5.94 | 1.0 | ✔ |
| P1-REV-02 | Tuerca baja ISO 4035 M12 A4-035: carga de prueba contra la precarga máxima | A_s 84,3 mm² × 350 MPa [ESTIMADO: ISO 3506-2, tuerca baja clase 035] contra 6.7 kN | 79.08 | metal | 350.0 | 4.43 | 2.0 | ✔ |
| P1-REV-02 | Brida Ø36 × 4 (dúplex): flexión por la precarga máxima | M' = F·(r_c − a)/(2π·a) = 6.7 kN × 3.4 / (2π·12); σ = 6·M'/t² | 113.24 | metal | 450.0 | 3.97 | 2.0 | ✔ |
| P1-REV-03 | Buje POM Ø20.1/Ø24 × 18: presión (R12, una traba) | 3302 N / (20 × 18) | 9.17 | metal | 20.0 | 2.18 | 2.0 | ✔ |
| P1-REV-03 | Buje POM: presión (reversa sizing, oscilación; una traba) | 1638 N / (20 × 18) | 4.55 | metal | 10.0 | 2.2 | 2.0 | ✔ |
| P1-REV-04 | Perno del émbolo Ø16 (316): flexión + corte con M_h completo (R12) | F = M_h/r = 3006 N a 6.5 mm | 59.61 | metal | 205.0 | 3.44 | 2.0 | ✔ |
| P1-REV-04 | Perno del émbolo: flexión (reversa sizing, fatiga; M_h completo) | F = 1491 N | 24.11 | metal | 180.0 | 7.47 | 2.0 | ✔ |
| P1-REV-04 | Cuerpo del émbolo Ø24/Ø16.2 (316) en la cara de la oreja: flexión + corte (R12, M_h completo) | M = 3006 N × 6.5 mm; τ = 2V/A (tubo) | 46.03 | metal | 205.0 | 4.45 | 2.0 | ✔ |
| P1-REV-04 | Perno Ø16 en la guía del cuerpo (316/316, H8/h9): aplastamiento con momento (R12) | p_máx = F/(d·L)·(1 + 6·a/L): L 22.5, a 16.25 mm; engrasar al montar (riesgo de engrane 316/316) | 44.54 | metal | 205.0 | 4.6 | 2.0 | ✔ |
| P1-REV-04 | Collar Ø32 × 1.5 del cuerpo: corte en la raíz con el empuje axial (cota μ·F) | F_ax = 0,3 × 3006 N = 902 N [μ SUPUESTO] / (π·24·1.5); τ·√3 | 13.81 | metal | 205.0 | 14.84 | 2.0 | ✔ |
| P1-REV-06 | Tornillo con hombro Ø8 de la varilla: flexión (palanca forzada) | F = 100 N × 125/46 = 272 N a 6 mm | 32.44 | metal | 205.0 | 6.32 | 2.0 | ✔ |
| P1-REV-09 | Perno de manivela Ø6 1.4401+C: flexión en la cara del cubo (eslabón sobre el eje del émbolo) | tiro de diseño 112 N por cable [CALCULADO: mano 100 N [SUPUESTO] × 35,4/15,9 / 2 cables, sin rozamiento; ≥ resorte 45,2 N [CALCULADO: k ESTIMADO] / (η Bowden 0,6 · η balancín 0,76) [ESTIMADOS]] a 22,3 mm del cubo | 117.27 | metal | 310.0 | 2.64 | 2.0 | ✔ |
| P1-REV-09 | Perno de manivela prensado en el cubo del balancín (5083): presión de apoyo bajo F·e | perno rígido en agujero de 12 mm, F 112 N a 22,3 mm de la cara: p = F/(d·L)·(4 + 6a/L) | 23.47 | metal | 125.0 | 5.33 | 2.0 | ✔ |
| P1-REV-09 | Balancín (alma 5 mm 5083): flexión del brazo junto al cubo del eje | 112 N a 7 mm; sección 8 × 5 | 14.65 | metal | 125.0 | 8.53 | 2.0 | ✔ |
| P1-REV-09 | Eje del balancín: presión en el casquillo Ø7 × 14 bajo el par F·e (+ cable de salida) | F 112 N a 20,3 mm delante del cubo: p = F/(d·L)·(4 + 6a/L) ⊕ cable | 14.83 | metal | 60.0 | 4.04 | 2.0 | ✔ |
| P1-REV-09 | Eje del balancín 1.4401+C: flexión del muñón Ø7 en la cara del montante | M = 112 N × 35,8 mm (eslabón) ⊕ cable = 4.02 N·m | 119.33 | metal | 310.0 | 2.6 | 2.0 | ✔ |
| P1-REV-09 | Eje Ø8 prensado en el montante 8 mm 5083: presión de apoyo | perno rígido en agujero de 8 mm, F 112 N a 35,8 mm ⊕ cable | 55.14 | metal | 125.0 | 2.27 | 2.0 | ✔ |
| P1-REV-09 | Montante 8 mm 5083: flexión fuera del plano por el par del eje (F·e) | M = 112 N × 35,8 mm en una franja de 16 × 8 (cubo r 8 del contorno) | 23.40 | metal | 125.0 | 5.34 | 2.0 | ✔ |
| P1-REV-09 | Ojo del eslabón 316: flexión de la pared de 2 × 5 sobre la ranura | M = F·l/4 = 112 N × 9,7/4 (perno en el centro de la ranura) | 81.19 | metal | 205.0 | 2.52 | 2.0 | ✔ |
| P1-REV-09 | Vástago M4 del eslabón (316): tracción | 112 N / A_s 8,78 mm² | 12.71 | metal | 205.0 | 16.13 | 2.0 | ✔ |
| P1-REV-09 | Tornillo M5 A4-70 de la base al pad de la boquilla: tracción (un cable tirando, eslabón a la altura del émbolo) | T = 112 N × 32,6 / 18 = 202 N / A_s 14,2 mm² | 14.23 | metal | 450.0 | 31.62 | 2.0 | ✔ |
| P1-CTL-14 | Gatillo 6 mm: flexión de la hoja en el cubo (100 N a 35,4 mm del pivote) | M = 100 N × 28,4 mm; sección 12 × 6 | 19.72 | metal | 240.0 | 12.17 | 2.0 | ✔ |
| P1-CTL-14 | Pasador Ø5 A4-70 del gatillo: flexión (mano + 2 cables; apoyo en la placa lateral del mango) | F = 323 N a 3,5 mm | 92.18 | metal | 450.0 | 4.88 | 2.0 | ✔ |
| P1-CTL-14 | Barra igualadora 316 5 × 4: flexión (dos cables a ±8 del pasador) | M = 112 N × 8 mm; sección 5 × 4 | 53.57 | metal | 205.0 | 3.83 | 2.0 | ✔ |
| P1-REV-05 | Soporte del Mach5: placa lateral en voladizo (palanca forzada) | 272 N a 48 mm; 6 × 124 | 0.85 | metal | 125.0 | 147.35 | 2.0 | ✔ |
| P1-CTL-09 | Palanca del acelerador: flexión en el cubo (100 N en el pomo) | M = 100 N × 120 mm; barra 16 × 8 | 35.16 | metal | 240.0 | 6.83 | 2.0 | ✔ |
| P1-CTL-10 | Palanca del bucket: flexión en el escalón (100 N en el pomo) | M = 100 N × 125 mm; 16 × 8 | 36.62 | metal | 240.0 | 6.55 | 2.0 | ✔ |
| P1-CTL-11 | Eje Ø12: torsión (100 N en el pomo del acelerador) | T = 15 N·m | 76.57 | metal | 205.0 | 2.68 | 2.0 | ✔ |
| P1-CTL-11 | Pasador Ø4 A4 palanca–eje: doble corte | F = T/d = 1250 N | 86.14 | metal | 450.0 | 5.22 | 2.0 | ✔ |
| P1-CTL-12 | Perno de enclavamiento Ø6: corte (palanca forzada contra el enclavamiento) | F = 100 N × 125 / 22 = 568 N | 46.41 | metal | 205.0 | 4.42 | 2.0 | ✔ |
| P1-CTL-08 | Placa central: aplastamiento del perno de enclavamiento (6 mm) | 568 N / (6 × 6) | 15.78 | metal | 125.0 | 7.92 | 2.0 | ✔ |
| P1-CTL-08 | Placa central: flexión bajo el eje (100 N en el pomo) | M = 100 N × 190 mm; sección 6 × 56 | 6.06 | metal | 125.0 | 20.63 | 2.0 | ✔ |
| P1-CTL-02 | Tapa PETG 6 mm: mano apoyada 150 N [SUPUESTO] (corta) | franja 50 × 6 apoyada, luz 50: M = F·L/4 | 6.25 | short | 24.0 | 3.84 | 3.0 | ✔ |
| P1-CTL-03 | Cara PETG 10 mm: tirón del cordón 150 N [SUPUESTO] (corta, cruza capas) | franja 50 × 10 empotrada, luz 76: M = F·L/8; ÷ f_Z (cara inclinada 32°) | 4.28 | short | 24.0 | 5.61 | 3.0 | ✔ |
| P1-CTL-03 | Cara PETG 10 mm: golpe sobre la seta 200 N [SUPUESTO] (corta, cruza capas) | ídem | 5.70 | short | 24.0 | 4.21 | 3.0 | ✔ |
| P1-CTL-01 | Placa de refuerzo 6 mm: carga del pasamuros del M66 | placa circular empotrada R 60, carga 279 N en r 10 | 12.34 | metal | 125.0 | 10.13 | 2.0 | ✔ |
| P1-CTL-04 | Pasamuros M66: cuerpo Ø20/Ø9,6 a tracción + flexión | 279 N; momento por 20 mm de voladizo | 8.67 | metal | 205.0 | 23.64 | 2.0 | ✔ |
| P1-INT-01 | Techo plano entre costados, p = máx(p_cierre, p_golpe) | placa larga empotrada: σ = p·b²/(2t²), b = W_open = 158, t = 5.0 | 33.74 | metal | 125.0 | 3.7 | 2.0 | ✔ |
| P1-INT-01 | Costado plano más alto (en el labio), p = máx(p_cierre, p_golpe) | placa empotrada brida–techo: σ = p·h²/(2t²), h = 156 | 32.69 | metal | 125.0 | 3.82 | 2.0 | ✔ |
| P1-INT-01 | Fatiga de la soldadura del costado: Δp = p_ram + p_succión = 42 kPa, 1e+05 ciclos | Δσ = Δp·h²/(2t²) vs FAT 25 (IIW, m = 3) → 68 MPa | 20.43 | metal | 67.9 | 3.32 | 2.0 | ✔ |
| P1-INT-01 | Bulones M6 A4 brida ↔ placa (14): precarga + p·A_abertura + 3 g | σ = (F_v + Φ·F/n)/A_s, F_v = 2200 N (2.4 N·m), F = 4456 N, Φ = 0,25 | 113.41 | metal | 450.0 | 3.97 | 2.0 | ✔ |
| P1-INT-02 | Rosca ciega M6 × 8 de la brida del conducto en 5083: barrido del filete | τ = (F_v + Φ·F/n)/(π·d·L·0,6), L útil = 6.5 mm, F_v = 2200 N vs τ_y = R_p0,2/√3 | 31.01 | metal | 72.2 | 2.33 | 2.0 | ✔ |
| P1-INT-02 | Junta brida del conducto ↔ placa: precarga M6 vs cordón NBR (1137 mm) + apertura | FS = F_v/((q_cordón·L + (1−Φ)·F)/n), q = 4 N/mm [ESTIMADO]; σ y S en N | 563.63 | metal | 2200.0 | 3.9 | 2.0 | ✔ |
| P1-INT-01 | Tubo junto a la brida de la bomba: momento del bucket (sin placa de espejo) | σ = M/(π r² t), M = F_bucket·358 | 3.13 | metal | 125.0 | 39.97 | 2.0 | ✔ |
| P1-INT-01 | Bulones M6 de la brida de la bomba: precarga + momento del bucket | σ = (F_v + Φ·4M/(n·r_bc))/A_s, Φ = 0,25 (VDI 2230) | 217.90 | metal | 450.0 | 2.07 | 2.0 | ✔ |
| P1-INT-01 | Tubo del eje en voladizo (sin contar el alma): caja del sello | σ = F·L/W, L = 74 | 2.34 | metal | 125.0 | 53.35 | 2.0 | ✔ |
| P1-INT-01 | Chimenea de inspección: presión de cierre (aro) | σ = p·r/t | 0.74 | metal | 125.0 | 169.02 | 2.0 | ✔ |
| P1-INT-02 | Paño lateral entre bulones del conducto y del ala: golpe de fondo | σ = p·b²/(2t²), b = 68 | 1.17 | metal | 125.0 | 106.56 | 2.0 | ✔ |
| P1-INT-02 | Tornillos M8 A4-70 del soporte (ISO 10642 desde abajo + tuerca): precarga + vuelco del empuje | σ = (F_v + Φ·F_t)/A_s, F_v = 6944 N (10 N·m, K 0.18), F_t = 458 N, Φ = 0,25 | 192.87 | metal | 450.0 | 2.33 | 2.0 | ✔ |
| P1-INT-02 | Asiento cónico de la cabeza M8 en el 5083 (aplastamiento) | σ_b = F/(π/4·(dk² − d²)), área PROYECTADA, dk = 16, F = F_v + F_t (auditoría Pass 3 H5) | 50.83 | metal | 125.0 | 2.46 | 2.0 | ✔ |
| P1-INT-02 | Arranque de la cabeza M8 a través de la placa (tapón de Ø dk sobre el cono) | τ = F/(π·dk·(t − h_cono)), t − h = 6.0 | 24.54 | metal | 72.2 | 2.94 | 2.0 | ✔ |
| P1-INT-02 | Bulones M6 del ala al casco (26): precarga + golpe de fondo + presión en la abertura | σ = (F_v + Φ·F/n)/A_s, F = 8758 N, Φ = 0,25 | 203.19 | metal | 450.0 | 2.21 | 2.0 | ✔ |
| P1-INT-02 | Aplastamiento del casco (Al 4 mm) por el empuje en los bulones del ala | σ_b = (T/n)/(d·t) | 1.23 | metal | 125.0 | 102.01 | 2.0 | ✔ |
| P1-INT-02 | Arranque de la cabeza avellanada M6 en el casco de 4 mm (corte del labio de 1,2 mm) | τ = (F/n)/(π·d_m·t_labio), d_m = 9 | 9.93 | metal | 72.2 | 7.27 | 2.0 | ✔ |
| P1-INT-03 | Barra con la rejilla tapada (bolsa) a la presión de cierre | viga simplemente apoyada L = 330, w = p·paso, W = 212 mm³ (sección perfilada) | 70.16 | metal | 205.0 | 2.92 | 2.0 | ✔ |
| P1-INT-03 | Barra: golpe de objeto 200 N en el centro | M = P·L/4 | 77.88 | metal | 205.0 | 2.63 | 2.0 | ✔ |
| P1-INT-03 | Apoyo de la barra contra la cuña de la placa (aplastamiento del Al) | σ_b = R/(b·9 mm) | 5.00 | metal | 125.0 | 24.98 | 2.0 | ✔ |
| P1-INT-04 | Tapa: succión/contrapresión de cierre (corta) | σ = 3(3+ν)p a²/(8t²), a = 58, t = 13.0 | 1.72 | short | 24.0 | 13.94 | 3.0 | ✔ |
| P1-INT-04 | Tapa: recuperación de presión a 30 km/h (sostenida) | ídem con p_ram | 0.63 | sust | 8.4 | 13.32 | 3.0 | ✔ |
| P1-INT-04 | Tapa: ciclo marcha ↔ punto fijo Δp = 42 kPa (olas/maniobras) | ídem con Δp | 1.07 | lcf | 3.6 | 3.34 | 3.0 | ✔ |
| P1-INT-04 | Tapa en la purga (r = 32, espesor neto 13.6): ciclo Δp (olas/maniobras) | σ_r = 3(3+ν)p(a² − r²)/(8t²) | 0.69 | lcf | 3.6 | 5.23 | 3.0 | ✔ |
| P1-INT-04 | Tapa: aplastamiento bajo arandela M6 Ø18 (sostenido) | σ = F/(π/4(18² − 6,4²)) | 0.30 | sust | 8.4 | 28.28 | 3.0 | ✔ |
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

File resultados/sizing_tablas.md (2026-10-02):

<!-- generado por sizing.py — no editar a mano -->

## Resumen

| Magnitud | Valor | Etiqueta |
|---|---|---|
| Estado del optimizador | sin_solucion_dura | [CALCULADO] |
| Motor / controlador / batería | Maytech MTI120116 150 KV (inrunner refrigerado por agua, 10–16S) / Flipsky FSESC 75350 con caja de agua (VESC, filtro de fase, IP65) / 2 × LiTime 36 V 60 Ah Golf Cart en paralelo (12S2P, BMS 2 × 120 A) | [CALCULADO: optimizador] |
| Masa total / LCG desde el espejo | 219 kg / 1.11 m | [CALCULADO] |
| Calado / GM / escora con el piloto 0,1 m a un lado | 287 mm / 10 mm / 76° | [CALCULADO] |
| Eje del impulsor bajo la flotación (cebado) | 172 mm (ceba) | [CALCULADO] |
| Impulsor / cubo / tobera | Ø132 / Ø66 / Ø87 mm | [CALCULADO] |
| Punto de diseño de la bomba | 43.5 km/h, 5073 rpm, φ 0.266, ψ 0.071, Ω_s 5.76 | [CALCULADO] |
| ¿Llega a planeo pleno (26.7 km/h) con la banda high? / margen mínimo 0–planeo pleno (a qué V) | NO / -8 % (26.6 km/h) — NO cumple el mínimo de 10% | [CALCULADO] |
| Puntos de planeo con Savitsky válido (L_K ≤ L_wl, λ ≤ 4, τ 2–15°) | 0 de 23 (el resto: limitado por eslora) | [CALCULADO; método ESTIMADO] |
| Tiempo de 0 a planeo pleno (banda nominal / alta) | 22.5 s / no llega | [CALCULADO] |
| ¿Se sostiene en planeo con potencia continua? (banda baja / nominal / alta) | sí / sí / NO | [CALCULADO; R ESTIMADO] |
| V máx. sostenida (potencia continua, banda nominal) | 24.0 km/h (objetivo 30) | [CALCULADO] |
| V máx. sostenida, banda baja – alta de R (sin validar hasta T4) | 17.6 – 28.3 km/h | [CALCULADO; R ESTIMADO] |
| P de batería a V máx. / a 5 kn | 6723 W / 1709 W | [CALCULADO] |
| Empuje a punto fijo / en reversa | 765 N / 217 N | [CALCULADO] |
| Autonomía a V máx. / a 5 kn | 37 min (14.8 km) / 2.4 h | [CALCULADO] |
| Energía de la misión requerida / nominal | 3381 / 4608 Wh | [CALCULADO] |
| Cavitación S a V máx. (límite) | 3.20 (3.5) | [CALCULADO] |
| Velocidad periférica máx. | 28.9 m/s | [CALCULADO] |
| Corriente pico de batería / límite de fase | 192 A / 292 A | [CALCULADO] |
| I_q pico (FOC) / l_current_max / margen | 287 A / 292 A / 2 % | [CALCULADO; convención bus_foc SUPUESTO] |
| Motor a V máx. sostenida (estacionario) | 49 °C (máx. 120) | [CALCULADO] |
| Eje Ø / FS estático / FS fatiga | 20 mm / 4.0 / 9.2 | [CALCULADO] |
| Rodamientos L10 a V máx. / vel. crítica / sello | 734057 h / 3.8× n máx. / 4.4 m/s | [CALCULADO] |

## Curva a fondo (potencia pico, banda de diseño, batería nominal)

| V [km/h] | R diseño [N] | T pico [N] | rpm | P bat [W] | I bat [A] | S | Limita |
|---|---|---|---|---|---|---|---|
| 0 | 0 | 765 | 4045 | 7373 | 192 | 3.50 | corriente de batería |
| 4 | 25 | 700 | 4047 | 7373 | 192 | 3.49 | corriente de batería |
| 7 | 115 | 642 | 4052 | 7373 | 192 | 3.48 | corriente de batería |
| 11 | 281 | 588 | 4059 | 7373 | 192 | 3.46 | corriente de batería |
| 14 | 443 | 538 | 4070 | 7373 | 192 | 3.43 | corriente de batería |
| 18 | 462 | 491 | 4083 | 7373 | 192 | 3.40 | corriente de batería |
| 22 | 449 | 447 | 4097 | 7373 | 192 | 3.36 | corriente de batería |
| 25 | 424 | 404 | 4113 | 7373 | 192 | 3.32 | corriente de batería |
| 29 | 413 | 362 | 4130 | 7373 | 192 | 3.27 | corriente de batería |
| 32 | 413 | 321 | 4147 | 7373 | 192 | 3.22 | corriente de batería |
| 36 | 423 | 279 | 4164 | 7373 | 192 | 3.15 | corriente de batería |
| 40 | 442 | 238 | 4182 | 7373 | 192 | 3.09 | corriente de batería |

## Triángulos de velocidad del impulsor

| Sección | r [mm] | u [m/s] | c_m [m/s] | β1 [°] | β2 [°] | desvío [°] | entrada estator [°] | de Haller |
|---|---|---|---|---|---|---|---|---|
| cubo | 33.0 | 17.5 | 9.3 | 28.0 | 41.3 | 13.3 | 53.5 | 0.71 |
| medio | 52.2 | 27.7 | 9.3 | 18.6 | 21.8 | 3.2 | 64.9 | 0.86 |
| punta | 66.0 | 35.1 | 9.3 | 14.9 | 16.5 | 1.5 | 69.7 | 0.91 |

## Optimizador (15 mejores)

| Motor | Batería | Ø imp | D_t/D | V máx [km/h] | Margen joroba | Costo [€] | Duras OK |
|---|---|---|---|---|---|---|---|
| HPM5000B_48 | LT36_60x1 | 132 | 0.74 | 14.0 | -48 % | 1322 | no |
| HPM5000B_48 | LT36_60x1 | 132 | 0.74 | 13.8 | -48 % | 1322 | no |
| HPM5000B_48 | LT36_60x1 | 132 | 0.70 | 13.8 | -48 % | 1322 | no |
| HPM5000B_48 | LT36_60x1 | 132 | 0.74 | 13.7 | -49 % | 1322 | no |
| HPM5000B_48 | LT36_60x1 | 132 | 0.70 | 13.7 | -48 % | 1322 | no |
| HPM5000B_48 | LT36_60x1 | 120 | 0.74 | 13.7 | -48 % | 1322 | no |
| HPM5000B_48 | LT36_60x1 | 132 | 0.66 | 13.6 | -47 % | 1322 | no |
| HPM5000B_48 | LT36_60x1 | 132 | 0.70 | 13.5 | -48 % | 1322 | no |
| HPM5000B_48 | LT36_60x1 | 120 | 0.74 | 13.5 | -48 % | 1322 | no |
| HPM5000B_48 | LT36_60x1 | 132 | 0.66 | 13.5 | -47 % | 1322 | no |
| HPM5000B_48 | LT36_60x1 | 120 | 0.70 | 13.5 | -47 % | 1322 | no |
| HPM5000B_48 | LT36_60x1 | 132 | 0.62 | 13.4 | -47 % | 1322 | no |
| HPM5000B_48 | LT36_60x1 | 120 | 0.74 | 13.4 | -48 % | 1322 | no |
| HPM5000B_48 | LT36_60x1 | 132 | 0.66 | 13.4 | -48 % | 1322 | no |
| HPM5000B_48 | LT36_60x1 | 120 | 0.70 | 13.4 | -47 % | 1322 | no |

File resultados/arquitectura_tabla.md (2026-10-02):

| Opción | seguridad (18 %) | concepto (12 %) | prestaciones (14 %) | eficiencia_5kn (8 %) | poca_prof (8 %) | viabilidad (10 %) | costo (10 %) | tiempo (7 %) | reparabilidad (6 %) | riesgo (7 %) | **Total** | Gana en MC |
|---|---|---|---|---|---|---|---|---|---|---|---|---|
| **B** Waterjet comercial AWT JT132 (Ø130) + el tren eléctrico de este diseño | 4 | 5 | 2 | 2 | 3 | 4 | 4 | 4 | 3 | 3 | **3.47** | 62 % |
| **C** Bomba de jet ski usada (Sea-Doo Spark 140) adaptada | 4 | 5 | 2 | 2 | 3 | 3 | 4 | 3 | 4 | 3 | **3.36** | 8 % |
| **E** Cola larga / surface drive (diseño P1 anterior, adaptado) | 3 | 1 | 2 | 4 | 5 | 4 | 4 | 3 | 5 | 3 | **3.18** | 17 % |
| **D** Fueraborda eléctrico de 3–6 kW con hélice | 2 | 1 | 4 | 4 | 2 | 5 | 2 | 5 | 2 | 5 | **3.04** | 14 % |
| **A** Waterjet propio (impulsor CNC + bomba Al + toma soldada) — este diseño | 4 | 5 | 2 | 2 | 3 | 2 | 3 | 2 | 3 | 2 | **2.96** | 0 % |
| **F** Hélice entubada en túnel bajo el casco (pump-jet / rim-drive) | 4 | 3 | 2 | 3 | 2 | 2 | 3 | 2 | 2 | 2 | **2.66** | 0 % |

Sensibilidad: variando cada peso ±50 % (renormalizado), el ganador **no cambia** en ninguno de los 20 casos.
Monte Carlo (20000 juegos de pesos Dirichlet alrededor de los nominales): B 62 %, C 8 %, D 14 %, E 17 %.

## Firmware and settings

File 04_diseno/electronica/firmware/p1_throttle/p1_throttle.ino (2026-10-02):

/*
 * p1_throttle.ino — Acelerador del waterjet de P1: bucket, limpieza de rejilla, perfiles y cadena de seguridad.
 * Placa: Arduino Nano (ATmega328P, 16 MHz, 5 V), bootloader NUEVO (Optiboot; FQBN arduino:avr:nano).
 *
 * [NO EJECUTADO en hardware]. Compilado con arduino-cli (ver README §Firmware). Probar en T0.
 *
 * La marcha atrás es el BUCKET (palanca + cable), no invertir el giro: el motor gira siempre en avance
 * y con el bucket abajo el comando se limita a reverse_limit. El único giro inverso es la limpieza de
 * rejilla (pulsador dedicado, acelerador en cero, <= 3 s, lento: l_min_erpm del VESC).
 *
 * La lógica (armado, rampa, zona muerta, bucket, limpieza de rejilla, perfil, dwell, fallas de sensor,
 * watchdog lógico) vive en src/throttle_logic.c (C99 puro, copia idéntica de ../throttle_logic.c,
 * testeada en PC con tests/test_firmware.py). Este sketch solo hace E/S:
 *
 *   A0  <- hall lineal ratiométrico A1324 de la palanca del acelerador (Vref = AVCC = 5 V = alimentación
 *          del sensor). Pull-down 100 kΩ externo: cable de señal o de 5 V cortado -> ~0 V -> FAULT.
 *   D2  <- cordón (INT0). INPUT_PULLUP + 10 kΩ externo; el transistor del opto U2 lo lleva a GND
 *          cuando la bobina del contactor está energizada (cordón Y seta cerrados).
 *          ALTO = kill (clip afuera, cable cortado, conector suelto, fusible de mando abierto).
 *   D3  <- seta de emergencia (INT1). Igual, opto U1 (nodo entre seta y cordón). ALTO = e-stop.
 *   D5  <- fin de carrera del BUCKET, NC a GND, INPUT_PULLUP + 10 kΩ externo. BAJO = cerrado = bucket
 *          ARRIBA; ALTO = bucket ABAJO o cable cortado (fail-safe: comando limitado a reverse_limit).
 *   D7  <- selector de perfil a GND, INPUT_PULLUP. BAJO = ABIERTO; ALTO (o cable cortado) = COSTA.
 *   D8  <- pulsador de limpieza de rejilla NA a GND, INPUT_PULLUP. BAJO = apretado.
 *   D12 -> perfil al VESC: ALTO = ABIERTO (l_max_erpm técnico); BAJO o MCU en reset = COSTA (5 kn).
 *          Pull-down 10 kΩ externo. [NO IMPLEMENTADO del lado del VESC: ver README §5.4]
 *   D9  -> PPM al VESC (Timer1/OC1A por hardware, 50 Hz, 1000–2000 µs, 1500 = neutro).
 *   D4  -> Q_EN: habilita el VESC llevando su entrada ADC2 (kill por software) a GND a través del
 *          opto U3 en serie. D4 BAJO o MCU en reset (alta impedancia) -> ADC2 en alto -> VESC en kill.
 *   D6  -> LED de estado del panel (espejo en D13).
 *   WDT de hardware 120 ms: si el lazo se cuelga, reset -> pines en alta impedancia -> sin PPM (timeout
 *          del VESC) y Q_EN abierto (kill del VESC); al reiniciar arranca DESARMADO.
 */
#include <avr/wdt.h>
#include <avr/interrupt.h>
#include <util/atomic.h>
#include <EEPROM.h>
#include "src/throttle_logic.h"

#ifndef P1_TEST_COMMANDS
#define P1_TEST_COMMANDS 0 /* 1 solo para T0 (habilita 'h' = colgar el lazo para probar el WDT) */
#endif

/* ------------------------------------------------------------------ pines y tiempos */
static const uint8_t PIN_HALL = A0;
static const uint8_t PIN_KILL = 2;   /* INT0 */
static const uint8_t PIN_ESTOP = 3;  /* INT1 */
static const uint8_t PIN_VESC_EN = 4;
static const uint8_t PIN_LED = 6;
static const uint8_t PIN_PPM = 9;    /* OC1A */
static const uint8_t PIN_BUCKET = 5;      /* fin de carrera NC: BAJO = bucket ARRIBA */
static const uint8_t PIN_PROFILE_SEL = 7; /* selector: BAJO = perfil ABIERTO          */
static const uint8_t PIN_WEED = 8;        /* pulsador de limpieza de rejilla: BAJO = apretado */
static const uint8_t PIN_PROFILE_OUT = 12;/* ALTO = perfil ABIERTO al VESC            */

static const uint16_t TICK_MS = 10;          /* [SUPUESTO: 100 Hz; corte por software <= 1 tick] */
static const uint16_t TELEMETRY_MS = 100;
static const uint8_t ADC_OVERSAMPLE = 4;     /* promedio de 4 lecturas (~0,45 ms) */
static const uint16_t PPM_PERIOD_US = 20000; /* [SUPUESTO: 50 Hz, trama RC estándar] */

/* ------------------------------------------------------------------ estado global */
static tl_config_t g_cfg;
static tl_ctx_t g_ctx;
static tl_outputs_t g_out;
static uint32_t g_last_tick_ms;
static uint32_t g_last_tele_ms;
static bool g_tele_on = true;
static volatile uint8_t g_isr_kill = 0;   /* flanco a "kill" visto por INT0 */
static volatile uint8_t g_isr_estop = 0;  /* flanco a "e-stop" visto por INT1 */
static uint8_t g_cal_step = 0;            /* 0 = sin calibrar en curso */
static uint16_t g_cal_center = 0, g_cal_fwd = 0, g_cal_rev = 0;
static uint8_t g_last_kill_ok = 1;    /* último kill_ok usado; 1 hasta que un tick confirme el cordón afuera */

/* Copia de MCUSR (causa de reset) y WDT apagado lo antes posible tras un reset por WDT.
 * `used` es OBLIGATORIO: el core arduino:avr compila con -flto y, sin él, el enlazador descarta esta
 * función (nadie la llama; solo está en .init3) -> tras un reset por WDT sin Optiboot el WDT seguiría
 * activo con 16 ms y el MCU quedaría en bucle de reset. Verificado con avr-objdump (tests/test_firmware.py). */
uint8_t g_mcusr __attribute__((section(".noinit")));
void p1_early_init(void) __attribute__((naked, used)) __attribute__((section(".init3")));
void p1_early_init(void)
{
    g_mcusr = MCUSR;
    MCUSR = 0;
    wdt_disable();
}

/* ------------------------------------------------------------------ PPM por Timer1 */
static inline uint16_t us_to_ticks(uint16_t us) { return (uint16_t)(us * 2u); } /* 16 MHz / 8 = 0,5 µs */

static void ppm_begin(void)
{
    digitalWrite(PIN_PPM, LOW);
    pinMode(PIN_PPM, OUTPUT);
    TCCR1A = 0;
    TCCR1B = 0;
    TCNT1 = 0;
    ICR1 = (uint16_t)(us_to_ticks(PPM_PERIOD_US) - 1u); /* TOP: 20 ms */
    OCR1A = us_to_ticks(g_cfg.ppm_center_us);           /* arranca en neutro */
    TCCR1A = _BV(COM1A1) | _BV(WGM11);                  /* OC1A no invertido, modo 14 (Fast PWM, TOP = ICR1) */
    TCCR1B = _BV(WGM13) | _BV(WGM12) | _BV(CS11);       /* prescaler 8 */
    /* En Fast PWM OCR1A tiene doble buffer: el cambio entra al inicio de la próxima trama (sin glitches). */
}

/* Corte inmediato desde las ISR: neutro + VESC en kill. Las ISR corren con interrupciones off,
 * así que la escritura de 16 bits de OCR1A es atómica. */
static inline void isr_cut(void)
{
    OCR1A = us_to_ticks(g_cfg.ppm_center_us);
    PORTD &= (uint8_t)~_BV(PD4); /* D4 = PIN_VESC_EN bajo */
}

ISR(INT0_vect) /* D2: cordón */
{
    if (PIND & _BV(PD2)) { /* ALTO = kill */
        isr_cut();
        g_isr_kill = 1;
    }
}

ISR(INT1_vect) /* D3: seta */
{
    if (PIND & _BV(PD3)) {
        isr_cut();
        g_isr_estop = 1;
    }
}

/* ------------------------------------------------------------------ calibración en EEPROM */
struct CalRecord {
    uint16_t magic;
    uint16_t rev, center, fwd;
    uint8_t crc;
};
static const uint16_t CAL_MAGIC = 0x5031; /* "P1" */

static uint8_t crc8(const uint8_t *p, uint8_t n)
{
    uint8_t crc = 0;
    while (n--) {
        crc ^= *p++;
        for (uint8_t i = 0; i < 8; i++) {
            crc = (crc & 0x80) ? (uint8_t)((crc << 1) ^ 0x07) : (uint8_t)(crc << 1);
        }
    }
    return crc;
}

static bool cal_load(void)
{
    CalRecord r;
    EEPROM.get(0, r);
    if (r.magic != CAL_MAGIC || crc8((const uint8_t *)&r, (uint8_t)(sizeof(r) - 1)) != r.crc) {
        return false;
    }
    return tl_calibrate(&g_cfg, r.rev, r.center, r.fwd) == TL_CFG_OK;
}

static bool cal_save(uint16_t rev, uint16_t center, uint16_t fwd)
{
    tl_config_t tmp = g_cfg;
    uint8_t e = tl_calibrate(&tmp, rev, center, fwd);
    if (e != TL_CFG_OK) {
        Serial.print(F("CAL: invalida, error 0x"));
        Serial.println(e, HEX);
        return false;
    }
    CalRecord r = {CAL_MAGIC, rev, center, fwd, 0};
    r.crc = crc8((const uint8_t *)&r, (uint8_t)(sizeof(r) - 1));
    EEPROM.put(0, r);
    g_cfg = tmp;
    tl_init(&g_ctx, &g_cfg); /* re-inicia DESARMADO con la calibración nueva */
    Serial.println(F("CAL: guardada. Volver la palanca a cero 1 s para armar."));
    return true;
}

/* ------------------------------------------------------------------ entradas */
static uint16_t read_hall(void)
{
    uint16_t acc = 0;
    for (uint8_t i = 0; i < ADC_OVERSAMPLE; i++) {
        acc = (uint16_t)(acc + (uint16_t)analogRead(PIN_HALL));
    }
    return (uint16_t)((acc + ADC_OVERSAMPLE / 2u) / ADC_OVERSAMPLE);
}

/* ------------------------------------------------------------------ LED de estado */
static void led_update(uint32_t now)
{
    bool on;
    const uint32_t f = g_out.flags;
    switch (g_out.state) {
    case TL_ARMED:
    case TL_RUN_FWD:
    case TL_RUN_REV:
    case TL_DWELL_ZERO:
        on = true;                                  /* fijo: armado */
        break;
    case TL_WEED:
        on = ((now / 100u) % 3u) != 0u;             /* parpadeo corto: limpieza de rejilla (giro inverso) */
        break;
    case TL_FAULT:
        on = ((now / 50u) & 1u) != 0u;              /* 10 Hz: falla (sensor/VESC/calibración) */
        break;
    default:                                        /* DESARMADO */
        if (f & (TL_F_KILL_CORD | TL_F_ESTOP)) {
            on = (now % 2000u) < 60u;               /* destello cada 2 s: cordón/seta abiertos */
        } else if (f & TL_F_NOT_ZERO) {
            on = ((now / 125u) & 1u) != 0u;         /* 4 Hz: volver el acelerador a cero */
        } else {
            on = ((now / 250u) & 1u) != 0u;         /* 2 Hz: contando 1 s en cero para armar */
        }
        break;
    }
    digitalWrite(PIN_LED, on ? HIGH : LOW);
    digitalWrite(LED_BUILTIN, on ? HIGH : LOW);
}

/* ------------------------------------------------------------------ consola serie (115200) */
static void print_help(void)
{
    Serial.println(F("Comandos: t=telemetria on/off, c=calibrar (solo con CORDON AFUERA), "
                     "1=centro 2=tope avance 3=tope atras (bucket ABAJO) s=guardar x=cancelar"
#if P1_TEST_COMMANDS
                     ", h=colgar lazo (prueba WDT T0)"
#endif
                     ));
}

static void serial_poll(void)
{
    /* UN carácter por vuelta de loop(): una ráfaga por USB no puede bloquear el lazo (cada respuesta
     * puede esperar ~10 ms a que se vacíe el buffer TX) hasta disparar el WDT con el motor en marcha. */
    if (Serial.available() > 0) {
        char ch = (char)Serial.read();
        const bool may_cal = (g_out.state == TL_DISARMED || g_out.state == TL_FAULT) && !g_last_kill_ok;
        switch (ch) {
        case 't': g_tele_on = !g_tele_on; break;
        case '?': print_help(); break;
        case 'c':
            if (!may_cal) { Serial.println(F("CAL: sacar el cordon (contactor abierto) y desarmar primero")); break; }
            g_cal_step = 1;
            Serial.println(F("CAL: soltar la palanca (centro) y enviar 1"));
            break;
        case '1': if (g_cal_step && may_cal) { g_cal_center = read_hall(); g_cal_step = 2; Serial.println(F("CAL: tope AVANCE y enviar 2")); } break;
        case '2': if (g_cal_step == 2 && may_cal) { g_cal_fwd = read_hall(); g_cal_step = 3; Serial.println(F("CAL: bajar el BUCKET, tope ATRAS y enviar 3")); } break;
        case '3': if (g_cal_step == 3 && may_cal) { g_cal_rev = read_hall(); g_cal_step = 4; Serial.println(F("CAL: enviar s para guardar")); } break;
        case 's':
            if (g_cal_step == 4 && may_cal) {
                Serial.print(F("CAL: rev/centro/avance = "));
                Serial.print(g_cal_rev); Serial.print('/'); Serial.print(g_cal_center); Serial.print('/'); Serial.println(g_cal_fwd);
                cal_save(g_cal_rev, g_cal_center, g_cal_fwd);
                g_cal_step = 0;
            }
            break;
        case 'x': g_cal_step = 0; Serial.println(F("CAL: cancelada")); break;
#if P1_TEST_COMMANDS
        case 'h':
            Serial.println(F("TEST: lazo colgado; el WDT (120 ms) debe reiniciar el MCU"));
            Serial.flush();
            for (;;) { /* sin wdt_reset(): reset por WDT */ }
#endif
        default: break;
        }
    }
}

static void telemetry(uint32_t now)
{
    /* CSV: t_ms,estado,adc,cmd,ppm_us,flags_hex,enable,perfil (flags: bit 0x2000 = bucket ABAJO) */
    Serial.print(now); Serial.print(',');
    Serial.print(tl_state_name(g_out.state)); Serial.print(',');
    Serial.print(g_ctx.prev_adc); Serial.print(',');
    Serial.print(g_out.cmd, 3); Serial.print(',');
    Serial.print(g_out.ppm_us); Serial.print(",0x");
    Serial.print(g_out.flags, HEX); Serial.print(',');
    Serial.print(g_out.enable); Serial.print(',');
    Serial.println(g_out.profile == TL_PROF_OPEN ? F("ABIERTO") : F("COSTA"));
}

/* ------------------------------------------------------------------ setup / loop */
void setup()
{
    /* Salidas seguras primero: VESC en kill, PPM bajo (sin pulsos). */
    digitalWrite(PIN_VESC_EN, LOW);
    pinMode(PIN_VESC_EN, OUTPUT);
    digitalWrite(PIN_PPM, LOW);
    pinMode(PIN_PPM, OUTPUT);
    digitalWrite(PIN_PROFILE_OUT, LOW);    /* perfil COSTA desde el primer instante */
    pinMode(PIN_PROFILE_OUT, OUTPUT);
    pinMode(PIN_LED, OUTPUT);
    pinMode(LED_BUILTIN, OUTPUT);
    pinMode(PIN_KILL, INPUT_PULLUP);
    pinMode(PIN_ESTOP, INPUT_PULLUP);
    pinMode(PIN_BUCKET, INPUT_PULLUP);
    pinMode(PIN_PROFILE_SEL, INPUT_PULLUP);
    pinMode(PIN_WEED, INPUT_PULLUP);
    analogReference(DEFAULT); /* AVCC = 5 V = alimentación del hall -> ratiométrico */

    Serial.begin(115200);
    Serial.print(F("P1 throttle v"));
    Serial.print(TL_VERSION >> 8); Serial.print('.'); Serial.print(TL_VERSION & 0xFF);
    Serial.print(F(" reset MCUSR=0x")); Serial.println(g_mcusr, HEX); /* 0x08 = WDRF (Optiboot puede dejarlo en 0) */

    tl_default_config(&g_cfg);
    if (!cal_load()) {
        Serial.println(F("SIN CALIBRACION VALIDA: estado FAULT hasta calibrar (c)."));
    }
    tl_init(&g_ctx, &g_cfg);
    g_out = g_ctx.last;

    ppm_begin(); /* pulsos neutros desde ya: el safe start del VESC los necesita */

    EICRA = _BV(ISC00) | _BV(ISC10); /* INT0 e INT1 en cualquier cambio (la ISR filtra el flanco a ALTO) */
    EIFR = _BV(INTF0) | _BV(INTF1);
    EIMSK = _BV(INT0) | _BV(INT1);

    print_help();
    wdt_enable(WDTO_120MS);
    g_last_tick_ms = millis();
    g_last_tele_ms = g_last_tick_ms;
}

void loop()
{
    const uint32_t now = millis();
    if ((uint32_t)(now - g_last_tick_ms) >= TICK_MS) {
        const uint32_t dt = now - g_last_tick_ms;
        g_last_tick_ms = now;

        tl_inputs_t in;
        uint8_t isr_kill, isr_estop;
        ATOMIC_BLOCK(ATOMIC_RESTORESTATE) {
            isr_kill = g_isr_kill;
            isr_estop = g_isr_estop;
            g_isr_kill = 0;
            g_isr_estop = 0;
        }
        uint8_t kill_ok = (digitalRead(PIN_KILL) == LOW) && !isr_kill;
        uint8_t estop_ok = (digitalRead(PIN_ESTOP) == LOW) && !isr_estop;
        /* Coherencia del cableado en serie: el nodo del cordón (D2) no puede estar energizado
         * si el de la seta (D3) no lo está -> falla de cableado/opto: tratar ambos como abiertos. */
        if (kill_ok && !estop_ok) { kill_ok = 0; }
        g_last_kill_ok = kill_ok;

        in.adc = read_hall();
        in.kill_cord_ok = kill_ok;
        in.estop_ok = estop_ok;
        in.vesc_ok = 1; /* [NO IMPLEMENTADO] telemetría UART del VESC (hook para P2) */
        in.bucket_up = (digitalRead(PIN_BUCKET) == LOW);      /* abierto/cortado = ABAJO */
        in.sel_open = (digitalRead(PIN_PROFILE_SEL) == LOW);  /* cortado = COSTA */
        in.weed_btn = (digitalRead(PIN_WEED) == LOW);

        g_out = tl_tick(&g_ctx, &in, dt);

        /* Aplicar salidas salvo que una ISR haya cortado después de leer las entradas:
         * en ese caso queda el neutro de la ISR y el próximo tick latchea el kill. */
        ATOMIC_BLOCK(ATOMIC_RESTORESTATE) {
            if (!g_isr_kill && !g_isr_estop) {
                OCR1A = us_to_ticks(g_out.ppm_us);
                if (g_out.enable) { PORTD |= _BV(PD4); } else { PORTD &= (uint8_t)~_BV(PD4); }
            }
        }
        digitalWrite(PIN_PROFILE_OUT, g_out.profile == TL_PROF_OPEN ? HIGH : LOW);
        wdt_reset(); /* solo tras un tick completo */
    }

    serial_poll();
    if (g_tele_on && (uint32_t)(now - g_last_tele_ms) >= TELEMETRY_MS) {
        g_last_tele_ms = now;
        telemetry(now);
    }
    led_update(now);
}

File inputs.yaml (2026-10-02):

# =============================================================================
# inputs.yaml — ÚNICA FUENTE DE ENTRADAS del proyecto P1-J (waterjet de Jorge)
# Todo el proyecto (cálculos, CAD, verificación, BOM, documentos) se regenera
# desde este archivo con:  python run_all.py
#
# Etiquetas (en el comentario de cada valor numérico):
#   [VERIFICADO: fuente]  dato leído en una fuente abierta en esta sesión
#   [CALCULADO]           resultado de un cálculo documentado
#   [ESTIMADO: base]      inferencia de ingeniería con base explícita
#   [SUPUESTO]            decisión de diseño / supuesto conservador
# Unidades SI salvo indicación; geometría en mm en las claves *_mm.
# Las decisiones y "qué cambia si el dato real difiere" están en decisiones.md
# El diseño anterior (cola larga para jon boat, 2 personas, 6 km/h) quedó en el
# historial de git (commit 5dfada0) y en decisiones.md §Historia.
# =============================================================================

meta:
  project: "P1-J — waterjet eléctrico inboard para el jet boat de Jorge (2,30 m)"
  version: "2.0"
  date: "2026-10-01"
  currency: "EUR"
  eur_to_dkk: 7.4755          # [VERIFICADO: BCE 2026-09-30, research/R08a §0]
  usd_to_eur: 0.8807          # [VERIFICADO: BCE 2026-09-30 (1 EUR = 1,1355 USD), research/R08a §0]

# -----------------------------------------------------------------------------
# CASCO — jet boat de Jorge (plano preliminar 26/09/2026, referencias/). Las vistas
# del plano no comparten escala (R10b §4.1): todo [ESTIMADO] hasta medir (PENDIENTES P0).
# x = hacia proa desde la cara exterior del espejo; z = hacia arriba desde la quilla.
# -----------------------------------------------------------------------------
boat:
  loa_m: 2.30                 # [VERIFICADO: plano de Jorge, cota "2300 largo total casco"]
  beam_m: 0.80                # [VERIFICADO: plano de Jorge, cota "800 ancho total casco"]
  lwl_m: 1.75                 # [ESTIMADO: research/R10b §4.3 — largo de fondo 1,73 m medido a escala]
  bottom_beam_m: 0.42         # [ESTIMADO: research/R10b §4.3 — fondo leído en la vista trasera (variante 0,60)]
  chine_beam_m: 0.69          # [ESTIMADO: research/R10b §4.3 — manga en el pantoque]
  chine_height_m: 0.25        # [ESTIMADO: research/R10b §4.3]
  gunwale_height_m: 0.52      # [VERIFICADO: plano de Jorge, cota 520 (vista trasera)]
  transom_height_m: 0.42      # [VERIFICADO: plano de Jorge, cota 420 en el espejo]
  deadrise_deg: 8.0           # [ESTIMADO: research/R10b §4.4 usó 5–10°; medir]
  planing_beam_m: 0.60        # [ESTIMADO: research/R10b §4.4 — manga de planeo media (b de Savitsky)]
  block_coeff: 0.80           # [ESTIMADO: coeficiente longitudinal ∇ = C·L·A_sección; R10b usó C_wp 0,85]
  waterplane_inertia_coeff: 0.065   # [ESTIMADO: research/R10b §4.3 — forma de flotación supuesta (70 % rectángulo + 30 % proa triangular); el cálculo es exacto, la forma no está medida]
  hull_mass_kg: 38.0          # [ESTIMADO: research/R10b §4.2 — 30–45 kg con cubierta, consola y asiento] — ÚNICA fuente: la usan masses.items.hull y la capacidad (33 CFR 183)
  bottom_thickness_mm: 4.0    # [SUPUESTO: casco de aluminio 4 mm; medir (la placa de la toma se ajusta)]
  transom_thickness_mm: 6.0   # [SUPUESTO: medir]
  floor_height_m: 0.075       # [ESTIMADO: research/R10a §5.2 — piso dibujado a 71–79 mm del fondo]
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

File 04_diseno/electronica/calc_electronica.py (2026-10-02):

#!/usr/bin/env python3
"""calc_electronica.py — Cálculos eléctricos y de la cadena de seguridad de P1.

Lee inputs.yaml (única fuente de entradas) y resultados/sizing.json (no hardcodea cargas) y produce:
  • 04_diseno/electronica/electronica.json   valores calculados (config VESC, precarga, bobina,
                                             optos, presupuesto de tiempo de corte, componentes)
  • 04_diseno/electronica/tabla_verdad.csv   enumeración COMPLETA de la cadena de habilitación
  • Bloques <!-- ELEC:nombre --> ... <!-- /ELEC:nombre --> del README.md de esta carpeta

Uso:  python 04_diseno/electronica/calc_electronica.py [--check]
      --check: no escribe; exit 1 si el README/JSON/CSV no coinciden con lo calculado.
Etiquetas: [VERIFICADO: fuente] · [CALCULADO] · [ESTIMADO: base] · [SUPUESTO].
"""
from __future__ import annotations

import csv
import io
import itertools
import json
import math
import re
import sys
from pathlib import Path

HERE = Path(__file__).resolve().parent
ROOT = HERE.parents[1]
sys.path.insert(0, str(ROOT))

VESC_SRC = "https://raw.githubusercontent.com/vedderb/bldc/master"
R06 = "research/R06_electrica.md"

# ----------------------------------------------------------------------------------------------
# Supuestos y datos propios de este módulo (todo lo demás sale de inputs.yaml / sizing.json)
# ----------------------------------------------------------------------------------------------
A = {
    "n_vs_power_exp": (1 / 3, "—", "[CALCULADO: bomba P ∝ n³ → n ∝ P^(1/3); con batería llena el límite de corriente de batería deja P × V_máx/V_nom]"),
    "lead_motor": ((13.30e-6, 0.30), "m², m", "[VERIFICADO: página Maytech MTI120116 — '6AWGx300mm'; 6 AWG = 13,30 mm² CALCULADO (fórmula AWG)]"),
    "lead_esc": ((8.37e-6, 0.20), "m², m", "[VERIFICADO: página Flipsky FSESC 75350 — 'Motor wire: 8AWG' (8 AWG = 8,37 mm² CALCULADO)]; largo 0,20 m [ESTIMADO: no publicado, medir]"),
    "v_cell_max": (3.65, "V", f"[ESTIMADO: {R06} §4.3, LFP 3,65 V/celda máx.]"),
    "v_cell_nom": (3.2, "V", f"[ESTIMADO: {R06} §4.3, LFP 3,2 V/celda nominal]"),
    "v_cell_cut_start": (3.0, "V", f"[ESTIMADO: {R06} §2.4, corte LFP 3,0 V/celda]"),
    "v_cell_cut_end": (2.8, "V", f"[ESTIMADO: {R06} §2.4, corte LFP 2,8 V/celda]"),
    "c_bus_f": (2.0e-3, "F", f"[ESTIMADO: {R06} §3.4, C de bus del VESC 1–2 mF no publicado; se toma el mayor]"),
    "r_pre_ohm": (100.0, "Ω", f"[SUPUESTO: {R06} §3.4 (100 Ω → 5τ ≤ 1 s)]"),
    "k1_model": ("TE Connectivity KILOVAC EV200AAANA", "—",
                 "[VERIFICADO: hoja EV200 Series (TE, 'KILOVAC EV200 Series Contactor', https://mm.digikey.com/Volume0/opasdata/d220001/medias/docus/5986/EV200_Series.pdf)]"),
    "k1_i_cont_a": (500.0, "A", "[VERIFICADO: hoja EV200 — 500 A @ 85 °C (400 mcm); 12–900 V CC]"),
    "k1_coil_range_v": ((9.0, 36.0), "V", "[VERIFICADO: hoja EV200 — bobina 'A' 9–36 V CC (opera), pickup máx. 9 V, dropout mín. 6 V]"),
    "k1_coil_hold_a": (0.13, "A", "[VERIFICADO: hoja EV200 — holding current 0,13 A @ 12 V (economizador incorporado, 1,7 W)]"),
    "k1_coil_inrush": ((3.8, 0.130), "A, s", "[VERIFICADO: hoja EV200 — inrush máx. 3,8 A, inrush time máx. 130 ms]"),
    "k1_release_ms": (12.0, "ms", "[VERIFICADO: hoja EV200 — release (incluye arco) máx. 12 ms @ 2000 A; close típ. 15 ms]"),
    "k1_back_emf_v": (0.0, "V", "[VERIFICADO: hoja EV200 — 'built-in coil economizer … limits back EMF to 0V']"),
    "k1_price_eur": (149.0, "EUR sin IVA", "[VERIFICADO: https://eveurope.eu/en/product/hoofdstroomrelais-ev200-500-amp-2/ — 149,00 € ex. VAT, 54 en stock, 2026-10-02]"),
    "v_ctl_nom": (12.0, "V", "[VERIFICADO: Mean Well RSD-60-SPEC (2026-07-09) — RSD-60L-12: 12 V, 5 A, entrada 18–72 V CC]; mando de K1 a 12 V (auditoría H3, R2-E1)"),
    "v_ctl_tol": (0.02, "—", "[VERIFICADO: Mean Well RSD-60-SPEC (2026-07-09) — tolerancia de salida ±2,0 %]"),
    "rsd_vin": ((18.0, 72.0), "V", "[VERIFICADO: Mean Well RSD-60-SPEC (2026-07-09) — 'VOLTAGE RANGE CONTINUOUS' L: 18 ~ 72 VDC (G: 9 ~ 36 VDC: NO sirve con 12S)]"),
    "rsd_i_out_a": (5.0, "A", "[VERIFICADO: Mean Well RSD-60-SPEC (2026-07-09) — RSD-60L-12 5 A; sobrecarga 105–135 % con limitación de corriente constante]"),
    "rsd_idle_w": ((0.5, 1.5), "W", "[ESTIMADO: consumo en vacío de un DC-DC aislado de 60 W; la ficha no lo publica — medir en T0.4]"),
    "bilge_i_a": ((2.0, 8.0), "A", "[ESTIMADO: Attwood Sahara S500 ≈ 2 A en marcha y ~4× en el arranque (motor CC); la ficha no se abrió]"),
    "k1_hold_min_v": (7.5, "V", "[VERIFICADO: hoja EV200 — Hold Voltage (Min.) 7,5 V CC (bobina 'A')]"),
    "hold_target_v": (9.0, "V", "[SUPUESTO: no bajar de 9 V (pickup máx. de la hoja EV200) durante el hueco: margen de 1,5 V sobre la retención mínima]"),
    "hold_t_s": (0.25, "s", "[SUPUESTO: hueco del riel de 12 V al arrancar la bomba de achique contra el límite de corriente del DC-DC (arranque < 0,1 s × 2,5); lo valida T0.4]"),
    "schottky_vf": (0.5, "V", "[ESTIMADO: Schottky 3 A (1N5822) a 0,2 A]"),
    "cap_std_mf": ((4.7, 6.8, 10.0, 15.0, 22.0, 33.0, 47.0), "mF", "[SUPUESTO: valores comerciales de electrolíticos ≥ 25 V]"),
    "batt_r_int_ohm": ((0.010, 0.050), "Ω", "[ESTIMADO: LiTime no publica la R interna (página 2026-10-02); 0,050 Ω = Power Queen 24 V 50 Ah 'R int. ≤ 40 mΩ' (R08a, VERIFICADO) escalada a 12S 60 Ah; 0,010 Ω = 12 celdas prismáticas de 60 Ah de ≈ 0,5 mΩ + BMS y bornes]"),
    "mrbf_aic_a": (2000.0, "A", "[VERIFICADO: research/R06_electrica.md §5.4 — MRBF 10 kA @ 14 V / 5 kA @ 32 V / 2 kA @ 58 V]"),
    "classt_aic_a": (20000.0, "A", "[VERIFICADO: Blue Sea 5113 Class T — '20,000 Ampere Interrupt Capacity (AIC)', 160 V CC máx. (fisheriessupply.com, 2026-10-02)]"),
    "brake_frac": (0.3, "—", "[SUPUESTO: corriente de frenado = 30 % de l_current_max (un jet casi no regenera; protege BMS)]"),
    "weed_rev_frac": (0.25, "—", "[SUPUESTO: giro inverso lento (≤ 25 % de las rpm de 5 kn) solo para soltar algas de la rejilla]"),
    "pump_P_T_exp": (1.5, "—", "[CALCULADO: bomba con T ∝ n², P ∝ n³ → P ∝ T^1,5; límite de par = P_frac^(2/3)]"),
    "opto_vr_max": (5.0, "V", "[ESTIMADO: V_R máx. del LED de optoacopladores de fototransistor típicos 5–6 V; verificar en la hoja del elegido]"),
    "diode_vf": (0.7, "V", "[ESTIMADO: diodo de silicio]"),
    "vih_frac": (0.6, "—", "[ESTIMADO: V_IH mín. ATmega328P = 0,6·Vcc (hoja de datos; no releída en esta sesión)]"),
    "vesc_iq_unknown": (None, "A", "[SUPUESTO: el consumo en reposo del VESC 75100 no está publicado; se mide en T0.3]"),
    "kill_switch_rating_a": (5.0, "A", f"[VERIFICADO: Sea Dog SD-420487-1, 5 A máx. ({R06} §3.2)]"),
    "f2_factor": (1.25, "—", "[SUPUESTO: fusible de mando (lento) ≥ 1,25 × corriente de cierre de la bobina]"),
    "opto_vf": (1.2, "V", "[ESTIMADO: LED IR de optoacoplador típico 1,1–1,4 V]"),
    "opto_if_target": (5.0e-3, "A", "[SUPUESTO: 5 mA a tensión nominal]"),
    "opto_ctr_min": (0.5, "—", "[SUPUESTO: especificación mínima de compra CTR ≥ 50 %]"),
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

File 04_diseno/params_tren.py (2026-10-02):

"""params_tren.py — parámetros del grupo TREN Y ELECTRÓNICA (P1-DRV-*, P1-MOT-*, P1-ELE-*).

Convención de estaciones: S = distancia a lo largo del eje hacia PROA desde la cara de entrada del
impulsor (marco JET: X = −S). Todas las piezas coaxiales se construyen en el marco JET.

Pila axial (de popa a proa), ver extend():
  muñón del buje de agua del estator (X_imp1 → X_aft) · ranura DIN 471 de retención a popa · asiento del
  impulsor Ø20 g6 con agujero de los semipasadores de corte (X = pmp_pin_X) · arandela + anillo DIN 471-20
  de empuje delante del impulsor (X = pmp_circlip_fwd_X) · tramo
  mojado Ø20 por el conducto · anillo DIN 471-20 de respaldo de la cabeza del sello · cabeza rotante
  del sello mecánico (en la cámara mojada de P1-DRV-02) · asiento fijo · linterna de goteo/testigo ·
  collar Ø26 (apoyo de los aros interiores) · 2 × 7204 BECBP en O · tuerca KM4 + MB4 · asiento del cubo
  del acople Ø20 con chaveta 6×6 · acople Rotex 24 · eje del motor · motor (cara de brida en S_motor0).

Secuencia de montaje (A-08: cada pieza pasa por los Ø de lo ya montado) — la verifican los checks de
P1-DRV-01:
  1. Banco: deslizar desde la PUNTA DE POPA del eje la caja del sello P1-DRV-02 (con el asiento fijo ya
     prensado) hasta el collar, y después la cabeza rotante hasta su anillo DIN 471 de respaldo.
     Pasan por: rosca M16, asiento del impulsor, ranuras (todo ≤ Ø20) → nunca por el collar Ø26.
  2. Bote: el subconjunto entra desde PROA, punta de popa primero, por el buje del sello de la toma
     (Ø seal_spigot_d), el conducto y el cubo del impulsor (ya puesto en el anillo de desgaste).
     Se centra el espigón de la caja en el buje y se aprietan los 4 × M6.
  3. Soporte de rodamientos P1-DRV-03 (auditoría Pass 3 H2: el alojamiento es cerrado y no puede bajar
     vertical sobre el eje): con las tuercas de los 4 espárragos SACADAS (tornillos ISO 10642 M8 × 35 A4-70
     colocados desde afuera en la placa base de la toma, cabeza enrasada en Sikaflex), el pórtico se apoya
     más a proa con el alojamiento delante de la punta de proa del eje (recorrido drv_brg_travel), con los
     espárragos de proa ya dentro de las RANURAS de las zapatas (abiertas hacia popa), y DESLIZA hacia popa
     a lo largo del eje (resalte Ø drv_brg_shoulder_hole sobre Ø20) hasta el fondo de las ranuras. Arandela
     ancha ISO 7093 + tuerca ISO 4032 A4 a mano. Rodamientos (2 × 7204 BECBP en O) prensados a la vez en el
     alojamiento y en el muñón desde proa (pasan por el asiento del acople y la rosca M20×1, ambos ≤ Ø20)
     contra el collar; aros interiores apretados por MB4 + KM4 contra el collar y aros exteriores entre el
     resalte y la tapa P1-DRV-06: con un par apareable universal (CB) el juego/precarga lo fija el
     rectificado del fabricante. Recién ahí se aprietan las tuercas M8 (drv_nut_torque_Nm, Tef-Gel) con el
     alojamiento alineado usando EL PROPIO EJE como mandril (auditoría R2-D07): estator presentado en la
     carcasa con el buje de agua, el eje libre en el buje (girarlo a mano), medir con galgas la luz eje ↔ buje
     arriba/abajo/±Y y mover el pórtico (±0,5 en las ranuras) hasta igualarlas; apretar, taladrar y escariar
     los 2 pasadores ISO 8735 Ø6 por zapata (toman el corte en x; la ranura no) y sacar el estator.
  4. Popa (grupo BOMBA): arandela + DIN 471 de empuje (ya en el eje desde el paso 1), impulsor, 2 semipasadores
     de corte, anillo retén P1-PMP-04 (2 × M3), arandela + DIN 471 de popa; estator; tobera (8 × M5).
  5. Cubo del acople en el eje (chaveta + prisionero), motor con su cubo y soporte P1-MOT-02.
"""
from __future__ import annotations

import math
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

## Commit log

2026-10-01 Pasada 1: CAD paramétrico build123d (33 piezas), build_all y verify_parts en verde
    Claude-Session: https://claude.ai/code/session_01NXXpTqtVV1Ju7qMEDzU6oG
    [P1-ASM_marcha.step, P1-DRV-01_shaft.step, P1-DRV-02_tube_bushing.step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]
2026-10-01 Pasada 1: structural.py (FS por pieza y caso), rediseños: caña sobre placa Al, tuercas cautivas, patín fusible, BOM
    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
    [P1-ASM_marcha.step, P1-DRV-01_shaft.step, P1-DRV-02_tube_bushing.step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]
2026-10-01 Pasada 1 completa: pipeline run_all exit 0, 34 piezas verificadas, FS, planos, BOM, docs, renders, 24 tests
    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
    [P1-ASM_marcha.step, P1-DRV-01_shaft.step, P1-DRV-02_tube_bushing.step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]
2026-10-01 Pasada 2: factores de material R05, placa motriz Al + cartucho, protector perfilado, antiventilación, kill switch por contactor, O-ring 3.53, 36 V como opción, apéndices en R(v)
    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
    [P1-ASM_marcha.step, P1-DRV-01_shaft.step, P1-DRV-02_tube_bushing.step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]
2026-10-01 Pasada 2: integra R07 (límite legal 5 kn, agua 24 °C, chalecos/equipo) y R08a (productos y precios verificados)
    - inputs.yaml: motor Flipsky 6374 BH, ESC Flipsky 75100 V2.0, baterías LiTime/Power Queen
    con precio, BMS, masa y cargador verificados; tipo de cambio BCE; IVA de importación
    - sizing: costo de selección = batería + cargador + hélice; tope de ERPM legal (modo costa);
    térmico del ESC en caja estanca → requisito de disipador
    - ELE-01: interior 160×110×45 (ESC + antichispa), prensaestopas M20 con rebaje a pared 5 mm,
    orejas en los lados largos; 10 cotas de verificación nuevas
    - bom.py: precios en DKK/USD, importación CN, alcance de equipo de operación aparte
    - dec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
    [P1-ASM_marcha.step, P1-DRV-01_shaft.step, P1-DRV-02_tube_bushing.step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]
2026-10-01 Pasada 2: integra R08b (BOM mecánica verificada) y corrige el montaje del eje
    - Eje: el muñón del rodamiento A quedaba entre dos tramos Ø16 (imposible de montar).
    Ahora tramo Ø15 continuo + hombro Ø16; pila apretada por tuerca M12 con separadores
    DRV-09/DRV-10 (nuevos, con planos); cota de montaje verificada en build_all
    - Rodamientos 6202-2RS (Biltema, verificado); cartucho Ø42/brida Ø56 con círculo de pernos
    paramétrico; rodamiento B flotante en el puente
    - Bujes igus iglidur H370 en portabujes PETG impresos (DRV-02)
    - Poleas y correas Dold con dientes/largos existentes; distancia entre centros real
    - Hélices: solo productos concretos (Minn Kota MKP-32 elegida; 10x8 queda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
    [P1-ASM_marcha.step, P1-DRV-01_shaft.step, P1-DRV-02_tube_bushing.step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]
2026-10-01 Pasada 2: integra R09 (B-series verificada, Burrill tabulado, factores de escala y térmicos)
    - p1calc/bseries_coeffs.json (39+47 términos verificados) + validez de rango; lineal
    recalibrada fuera de rango; efficiency_factor 0,95 (ITTC-78/Holtrop)
    - Burrill: curva de 5 % por interpolación (el ajuste anterior no era conservador)
    - Motor: R en caliente ×1,236; límite térmico 85 °C (VESC); paso de pala ±20 %
    - Fatiga del pasador de corte en crucero; desempate por ≤ 3 % de autonomía
    - structural: largo de agarre del tubo en la cuna corregido
    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
    [P1-ASM_marcha.step, P1-DRV-01_shaft.step, P1-DRV-02_tube_bushing.step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]
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2026-10-01 Visor 3D web (04_diseno/visor): generador de mallas/datos desde el CAD + página three.js con ensamblaje, explosión, ficha por pieza y demo
    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
    [P1.1A_peine_agujeros_12_20.step, P1.1A_peine_agujeros_12_20.stl, P1.1B_peine_agujeros_24_40.step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]
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2026-10-01 Integra salidas de agentes: docs 01/03/06/07/checklist, electrónica completa, FEA, probetas, perfiles PrusaSlicer, análisis del plano waterjet (R10a/R10b)
    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
    [P1.1A_peine_agujeros_12_20.step, P1.1A_peine_agujeros_12_20.stl, P1.1B_peine_agujeros_24_40.step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]
2026-10-01 Pasada 2: restricción térmica del motor en crucero (60 A, poleas 20:48), V mín = corte del VESC, tope legal de ERPM en la config. del VESC, DC-DC del MCU en la BOM, 2.º prensaestopas de señal, run_al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
    [P1-ASM_marcha.step, P1-DRV-01_shaft.step, P1-DRV-02_tube_bushing.step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]
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2026-10-01 Pasada 3 (WIP): correcciones de propulsión y comparación generada
    - Bollard neto (deducción + aro), térmico sostenido desde T de crucero, pico de
    batería sobre todas las V máx, margen ESC vs corriente de fase, reversa en inputs
    - Sensibilidad con D/P de hélice, R_th y aire (T de motor por entrada)
    - Disipador del ESC por el caso V máx sostenida; caso legal 2 personas batería llena
    - comparacion.py + resultados/comparacion.json (marcadores cmp.*), README corregido
    - Checkpoint con correcciones de subsistemas en curso
    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
    [P1-ASM_marcha.step, P1-DRV-01_shaft.step, P1-DRV-02_tube_bushing.step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]
2026-10-01 Rediseño a waterjet inboard (WIP): núcleo de cálculo, inputs y marco CAD
    - Nuevo inputs.yaml para el jet boat de Jorge (casco 2,30 × 0,80 m, 1 piloto,
    5 kW continuos, objetivo 30 km/h, 5 kn dentro de 300 m)
    - p1calc: hull (hidrostática, GM, capacidad 33 CFR 183.33), planing (joroba +
    Savitsky vía openplaning), waterjet (cantidad de movimiento + bomba axial con
    característica fuera de diseño, cavitación S, motor directo)
    - sizing.py: optimizador motor × controlador × batería × Ø impulsor × tobera ×
    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
    [P1-ASM_marcha.step, P1-DRV-01_shaft.step, P1-DRV-02_tube_bushing.step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]
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2026-10-01 params: el eje sale de la toma a 1,85·D (techo de curvatura continua libra la caja del sello)
    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
    [P1-DRV-01_shaft.step, P1-DRV-02_seal_housing.step, P1-DRV-03_bearing_bracket.step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]
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2026-10-01 Tren y electrónica del waterjet: eje, sello, pórtico de rodamientos, acople, motor, ESC, config VESC
    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
    [P1-DRV-01_shaft.step, P1-DRV-02_seal_housing.step, P1-DRV-03_bearing_bracket.step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]
2026-10-01 Ensamblaje STEP versionado comprimido (.step.gz) para no superar el límite de GitHub
    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
    [P1-PMP-03_impeller.step, P1-PMP-04_pin_band.step, P1-PMP-05_shear_pin.step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]
2026-10-01 CAD del waterjet (WIP): avances de toma, bomba y dirección
    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
    [P1-REV-02_perno_bucket.step, P1-REV-03_buje_bucket.step, P1-REV-04_embolo.step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]
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2026-10-01 Bomba del waterjet: carcasa, anillo de desgaste, impulsor de 5 álabes, pasador de corte, estator con buje de agua, tobera y placa de espejo
    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
    [P1-CTL-01_placa_espejo.step, P1-CTL-02_caja_acel.step, P1-CTL-02_caja_acel.stl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]
2026-10-01 Toma del waterjet: conducto Al 5083 soldado, placa base enrasada, rejilla 316 a proa del impulsor, tapa de inspección, casco de referencia
    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
    [P1-CTL-01_placa_espejo.step, P1-CTL-02_caja_acel.step, P1-CTL-02_caja_acel.stl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]
2026-10-01 Dirección, reversa y mandos: boquilla, yugo, bucket con traba, cables Ultraflex, consola con enclavamiento, kill switch
    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
    [P1-CTL-01_placa_espejo.step, P1-CTL-02_caja_acel.step, P1-CTL-03_soporte_kill.step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]
2026-10-01 Integración waterjet: matriz de arquitectura (gana comprar la JT132), comprar vs construir, decisiones nuevas, holgura de punta 0,4 mm
    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
    [P1-CTL-01_placa_espejo.step, P1-CTL-02_caja_acel.step, P1-CTL-03_soporte_kill.step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]
2026-10-01 Waterjet (WIP): correcciones de geometría, BOM y firmware en curso
    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
    [P1-INT-01_conducto.step]
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2026-10-01 Bomba: orejas de pivote en la placa de espejo con bujes POM, geometría válida para toda la gama de toberas
    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
    [P1-CTL-01_placa_espejo.step, P1-CTL-02_caja_acel.step, P1-CTL-03_soporte_kill.step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]
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2026-10-01 Dirección/reversa cerradas (topes, desbloqueo del bucket), BOM del waterjet, firmware con bucket y perfiles, batería en el CAD, visor nuevo (WIP)
    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
    [P1-CTL-01_placa_espejo.step, P1-CTL-02_caja_acel.step, P1-CTL-03_soporte_kill.step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]
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2026-10-19 argos-engine: rocket concept picture, independently checked
    Render and to-scale side view of the whole rocket around the frozen
    engine CAD v3.5.1 (both PASS on independent check, one label wording
    fixed), corrected real-world examples (v1.1 after verification), and
    the image gallery page with the new section. Airframe is the ASSUMED
    GNC reference vehicle; tank is a concept; not physical approval.
    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
2026-10-19 argos-engine: GNC rev4 staged for independent check
    GNC rev4 staging (MANIFEST_rev4 083675a6abddaabe): A1 apogee 210 m
    holds on CAD v3.5.1, ENG-11 gimbal stiffness requirement (K_s >= 100
    N m/rad at B-TVC-1 plus a measured airframe bending mode), RE-24 jam
    cases, payload sensitivity (0.5 kg at 190 m with the 2.0 kg tank; 1 kg
    at 210 m needs 2.2 kg N2O) and v3.2 proposals. Not gnc.json; awaits
    the REV-GNC-5 delta re-check. Simulation only.
    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
2026-10-19 argos-engine: 3D assembled FEA F1 final on corrected connectors (CHANGELOG 220)
    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
2026-10-20 argos-engine: independent review of the 3D FEA (REV-MECH-2, REVISE) and lead disposition (CHANGELOG 234)
    REV-MECH-2 reviewed the FEA3D assembled-engine 3D FE on CAD v3.5.1:
    verdict REVISE (no blocking item; three major: the J-FWD hole value is an
    idealisation number, the regular-node rule hides negative all-node values,
    and the with-servo gimbal stiffness is wrong off-centre). Line 234 adopts
    every finding, rules the LC2 / LC2F factor question and the J-FWD screw
    preload basis, and records the nozzle-foil footprint change and the
    thermal gap-conductance variant. The 3D FEA re-check of the v3.5.2 parts
    applies these corrections.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
2026-10-20 argos-engine: v3.5.2 interim rev 4 case with the screw spot faces, seat sub-model rev 4, J-FWD joint checks (CHANGELOG 237)
    - 03-cad/v3.5.2: TC-01 with ten d10.5 flat spot faces for the J-FWD screw
    heads (wall 2.688 mm at the hole, -0.505 g); hardware v1.5 text fixes
    (HW-101 head seat, HW-150 O-ring size from the maker's table).
    MANIFEST 202 rows (sha256/16 5b2bd906c999d62d).
    - 04-fea/v352: preload loss after embedding, fit-gap and contingency-fit
    rows, forward gland extrusion check, case mid-bay LCF and preload checks,
    and the rev-4 S-AX seat sub-model tables (sax_r4/). MANIFEST 61 rows
    (9b6a92abb8e7602b).
    - interfaces/CHANGELOG.md line 237 (Mechanical).
    Simulation and hand-cal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
2026-10-20 argos-engine: v3.5.2 interim hardware v1.6, massdelta v7, J-FWD relaxation v2 and gland-1 v2 (CHANGELOG 238), lead decisions after line 236 (CHANGELOG 239)
    - 03-cad/v3.5.2: hardware v1.6 (HW-150 sourced O-ring size), BOM and massprops updated, massdelta v7; MANIFEST 212 rows, sha256sum -c OK.
    - 04-fea/v352: J-FWD relaxation v2 (shell stiffness re-calibrated to the spot-face FE), gland-1 v2 (second-maker extrusion chart, O-ring passage over the screw holes); MANIFEST 73 rows, sha256sum -c OK.
    - interfaces/CHANGELOG.md: Mechanical's line 238 and the lead's line 239 (J-FWD requirement and secondary wall bending, TB-state safety factors, js5 soak rows, O-ring passage fix, open items).
    Simulatio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
2026-10-20 argos-engine: J-FWD screw fix to IN718 M5, js5 full post, soak envelope, relaxation v4 (CHANGELOG 240)
    - 04-fea/v352 (Mechanical, MANIFEST_v352.sha256 5e8fd83fcaa5d372, 98 rows):
    FA1S screw criterion and fix options (jfwd_fix v2), relaxation v3 and v4,
    gland-1 basis check (gland_fwd v3), O1 on the spot-face wall (jfwd_v352 v2).
    - 04-fea/assembly3d_v352 (FEA3D): js5 full post (jfwd_interim INDEX
    76f9852492a597dd), land-A fit-closure superposition.
    - interfaces/CHANGELOG.md line 240: lead decisions 09:57Z-12:31Z (IN718 M5
    screw, hole edge break R0.1-R0.2, gland-1 closed with no back-up ring,
    fit closure closed, sharp-edge soak envelope, seat-line slack open,
    FEA3D run order).
    Co-A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
2026-10-20 argos-engine: J-FWD re-map on envelope v3, (b) package and abort, lead rulings (CHANGELOG 242-243)
    - 04-fea/v352 (MANIFEST_v352.sha256 5fa1e679a4c4447f, 165 rows, sha256sum -c OK):
    relax v7, IN718 rows v6 (drawn M5 x 10.2 basis), screw LCF v2, disc spring v3,
    K_js5 embedding / fit re-run, the (b) package with the abort recommendation
    (bpkg_abort_v352_v1.json), item C / T-F1 texts v2, T-F2 rev 4, and the
    superseded rows v5 kept in history/ as a record.
    - 04-fea/REPORT-MECHANICAL-v3.5.2-HANDBACK-1646Z.md: Mechanical's handback
    text, placed by the lead as the record.
    - interfaces/CHANGELOG.md: Mechanical line 242 and lead line 243 (abort
    A = 150 C on the case TC station; slack fix r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
2026-10-20 argos-engine: rev-5 CAD check, J-F1 cap and lead rulings (CHANGELOG 244-245)
    Mechanical's line 244 records the rev-5 J-FWD CAD check (software check).
    Lead line 245 records the 17:16-18:37Z rulings: the c71 live-reader
    scope, the cone-pose K band with its corrected pair check, the J-F1
    maximum preload cap at 3750 N, registration, head form, axial basis and
    clocking for the disc-spring fix, the MJ Kf box (not sourced), Mechanical's
    rows v7 (accepted) and the chain E tail order. The open negatives are
    unchanged.
    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
2026-10-20 argos-engine: released c71 fields note and pre-fix samples.py (FE chain E end)
    FEA3D's end-of-chain-E hub items in 04-fea/assembly3d_v352/: the note
    listing the nine superseded v3.5.1 c71 pose fields released to free disk,
    each with its size, raw sha256, R3 replacement run, kept files and the
    regeneration recipe; and the pre-fix samples.py used when those decks
    were built. No existing hub file changed.
    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
2026-10-20 argos-engine: final CAD part set v3.5.2 (Mechanical publication 2)
    - 03-cad/v3.5.2: the final set, MANIFEST a94851ae4dc22cc4 (441 rows,
    sha256sum -c OK). All 112 part numbers as STEP + STL (100 added),
    assembly neutral / stop045 STEP and GLB, BOM (107 lines; adds the
    HW-170 disc spring and the GSE items ENG-TC-12 / ENG-TC-13), hardware
    v1.7, mass properties (engine mid 2.738 kg), mass delta v9 vs v3.5.1
    (landing -0.066 kg, CALC, not weighed), src rev 5 and checks.
    Replaced files are kept under history/.
    - interfaces/mechanical.json v2.2 (v2.1 kept in 03-cad/v3.5.2/history/).
    - interfaces/CHANGELOG.md line 247 (Mechanical's publication record).
    CAD and simulation results only; no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
2026-10-20 argos-engine: CAD v3.5.2 rebuild proof and archive inputs (Mechanical publication 3)
    Mechanical's one publish to 03-cad/v3.5.2 after the lead's rulings of
    2026-10-20 19:53Z, 20:16Z and 20:30Z (no CHANGELOG line for it):
    - src/engmat.py (material library v1.7, adds FLEX-GRAPHITE-TH for the
    NZ-06 foil), src/calcs/hose_frame.py, src/calcs/hardware_v351.py
    - checks/rebuild_from_hub_v352.py and its record
    checks/rebuild_from_hub_v352_v2.json (ALL_OK true)
    - set_v3.5.2.json updated (engmat, archive inputs, rebuild elsewhere,
    rebuild proof); the previous set file and manifest kept in history/
    - MANIFEST_v3.5.2.sha256: 448 rows, sha256sum -c OK
    Proof scope: the v3.5.2 set rebuilds from the h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
2026-10-21 argos-engine: lead CHANGELOG line 249
    Lead decisions from 2026-10-20 21:17Z to 2026-10-21 03:19Z: case-TC abort
    channel accepted (A = 150 C), stand T0 <= 24 C rule, T-F1 basis on the A 175
    rows, relight refusal 130 C, Pc transducer proof >= 166 bar abs, TC-04 stays
    a found negative (BT), OP-moment artefact and hole-load rule, J-FWD envelope
    v4 adopted, seat-line P+Q select-fit band applies, mesh correction C1,
    convergence check cD on the final TC-01, FE seat handover, js5b done.
    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
2026-10-21 argos-engine: CHANGELOG 253, Electronics v2.11 review, electronics.json v4
    Independent review REV-ELEC-3 of Electronics v2.11: ACCEPT WITH COMMENTS
    (0 blocking, 1 major, 5 minor, 10 notes). The review text is saved as
    reviews/REVIEW-ELECTRONICS-R3.md with the reviewer's scripts and data in
    reviews/electronics/r3/ (MANIFEST_REV-ELEC-3.sha256, 31 entries).
    interfaces/electronics.json is promoted from v3 to v4 (the staged
    results/electronics_v4.json). The major finding R3-01 stays open: the C1
    pressure-transducer re-zero and BASE limits are not re-derived for the C1
    thermal zero drift, so those two constants are not accepted and the A1
    BASE_AMB decision is held for the next Electronics round.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
2026-10-21 argos-engine: Combustion v2.4c and lead line 257
    Publishes Combustion v2.4c, the lead's text-only fold of the REV-COMB-4
    corrections and of the decisions in CHANGELOG lines 227-256:
    combustion.json v2.4c, REPORT section 17, CF-4 spec v2.2, T1-T4 spec
    v3.1, the annotated R3 response and the datasheet inputs, with the
    writer script. The v2.4b set is archived under superseded/v2p4b with
    its hashes. CHANGELOG line 257 records the publication and a new purge
    condition: after the cold-flow test the purge time and cap are re-set
    from the measured flow, so the warm-end vent stays within the 76 g
    basis. No model was re-run. Simulation and calculation only; nothing
    here is physical approval.
    Co-Autho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
2026-10-21 argos-engine: guidance file v3.2, J-FWD follow-ups, lead lines 258-260
    Publishes gnc.json v3.2: the staged candidate with the 34 corrections
    of the independent guidance re-check REV-GNC-7 (review saved as
    reviews/REVIEW-GNC-R5.md with its reviewer files under
    reviews/gnc/rev4b), applied by the lead, matched byte for byte to the
    reviewer's trial, and post-checked. The servo stiffness design-to
    window narrows to 100-110 N m/rad on the final CAD plant and is not
    robust across servo inertia. v3.1 is archived; the GNC datasheet
    inputs v3.2 are new.
    Adds Mechanical's J-FWD follow-ups: the torch-passage tap wall at the
    151 bar abs design case (closes the combustion review item), the
    restated start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
2026-10-21 argos-engine: Combustion v2.4d and lead line 261
    Publishes Combustion v2.4d, the lead's text-only fold of CHANGELOG
    lines 258-260: the adopted Z3 v2 pressure zone and the J-FWD joint
    replace rule on Q_JFWD, the two purge re-set checks (d1) / (d2), and
    the published torch-port wall row, which closes R4-01. The guidance
    team's answer in gnc.json v3.2 lets the T4 static-fire test shrink to
    the shortest firing (about 2.0 kg of N2O, an estimate); its table rows
    wait for a Combustion re-run. Files: combustion.json v2.4d, REPORT
    section 18, CF-4 spec v2.3, T1-T4 spec v3.2, the datasheet inputs and
    the writer script; the v2.4c set is archived under superseded/v2p4c
    with its hashes. No model was re-r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
2026-10-21 argos-engine: Electronics v2.12 staged and lead lines 262-264
    Adds the Electronics v2.12 round as a staged candidate in
    06-electronics/staging_v2.12 (85 files, with SHA256SUMS-v2.12):
    the seat-temperature compensation of the chamber-pressure zero,
    the electronics.json v4.1 candidate, bench plan v5 and BOM v2.4.
    The candidate waits for its independent review (REV-ELEC-4), so
    interfaces/electronics.json stays v4 until the verdict. Also adds
    the datasheet reviewer's phase A files in reviews/datasheet/r1
    (one review script is held back from this public archive) and
    CHANGELOG lines 262-264: three agents at a time, and the lead
    rulings on the sensor drift fix, the torch pressure sensor
    upgrade, th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
2026-10-21 argos-engine: final package with datasheet rev1 and line 268
    Adds the final engine package. The technical datasheet, PRELIMINARY
    rev1 (07-datasheet/out/rev1/, 161 pages), is built from CAD v3.5.2
    with every value traced to its source; its generator v0.3.1, the
    v3.5.2 renders and the independent check of the final build
    (REV-DS-1) come with it. Also adds the Electronics v2.12 review
    (REV-ELEC-4) with its artefacts, interfaces/electronics.json v4.1
    as promoted, both reviews in reviews/SUPERVISION.json, CHANGELOG
    lines 265-268 and an updated README.
    The A1 flight stays NO-GO until the ignition firmware fix v2.13 is
    reviewed; that fix follows in a later push. Not included: the
    datasheet's rev1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
2026-10-21 argos-engine: firmware v2.13 accepted, carve-out lifted (line 270)
    Adds the Electronics firmware v2.13 delivery (06-electronics/
    staging_v2.13/: the ignition fix for the C1 seat temperature sensor,
    its SIL runs, the interfaces file v4.2, bench plan v5.1 and BOM v2.5),
    its independent review REV-ELEC-5 (accept with comments, no blocking
    finding) with its artefacts, interfaces/electronics.json v4.2 as
    promoted, the review in reviews/SUPERVISION.json, CHANGELOG lines
    269-270 and an updated README.
    Line 270 lifts the restriction on the seat-temperature correction
    for starts with ignition and governs v4.2 and bench plan v5.1 where
    they differ. The A1 flight stays NO-GO until the five items in li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
